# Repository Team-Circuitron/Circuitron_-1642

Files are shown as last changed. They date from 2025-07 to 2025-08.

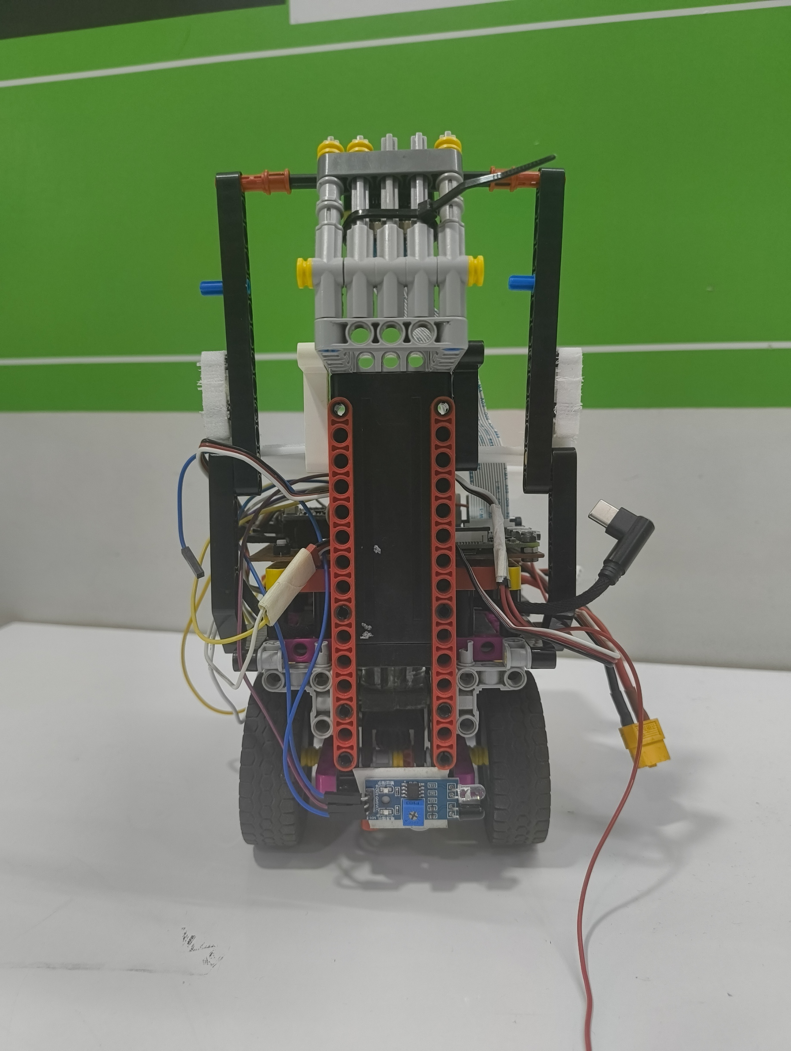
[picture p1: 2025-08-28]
v-photos/back view.jpg

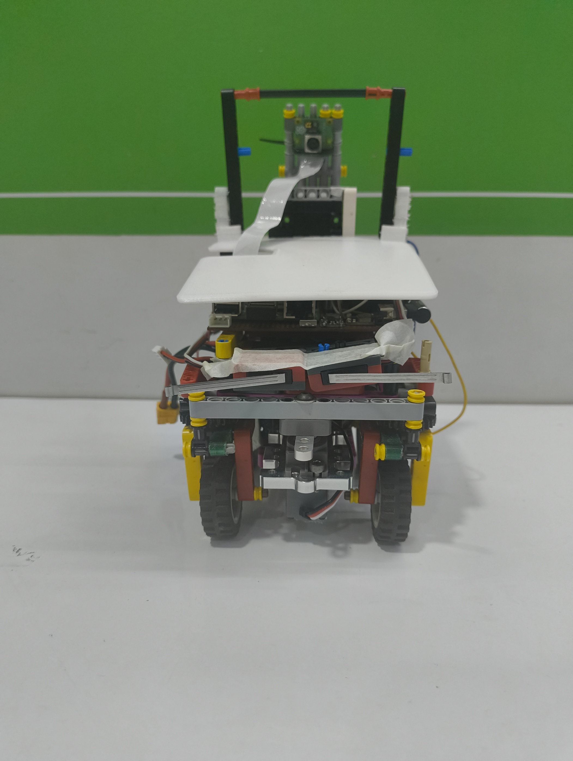
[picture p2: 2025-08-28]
v-photos/front view.jpg

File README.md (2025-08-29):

# Circuitron_#1642
**Contemplate · Create · Conquer**

This repository contains details about the design, evolution, and continuous development of our self-driving robot vehicle, built and programmed by Team Circuitron for the Future Engineers 2025 category of the World Robot Olympiad (WRO).

---

## Member Details
1. Pranay Agarwal (Software)  
2. Aditya Parikh (Hardware)  
3. Paritra Gada (Hardware)

---

## Table of Contents

- `t-photos`: Contains 2 photos of the team, including an official and a funny photo  
- `v-photos`: Contains 6 photos of the vehicle from all sides, including top and bottom views  
- `video`: Contains a `video.md` file linking to a video showing the robot in action  
- `Hardware`  Includes hardware overview, design process, final design, and component choices  
- `Code`: Includes all source code controlling the vehicle's behaviour 
- `Strategy`: Explanation of wall-following logic and decision-making approach  
- `models`  Files for 3D printing, laser cutting, or CNC (if applicable)  
- `other`: Supporting documents like connection instructions, datasets, specs  
- `special-thanks`  Acknowledgements and credits

---
## Engineering Notebook
Our engineering notebook contains more information about our robot and can be found here:

## Hardware Overview
---

## Table of Contents
1. [Hardware Overview](#hardware-overview)
2. [Processing Unit](#processing-unit)
3. [Vision System](#vision-system)
4. [Locomotion](#locomotion)
5. [Steering System](#steering-system)
6. [Power Management](#power-management)
7. [Chassis](#chassis)
8. [License](#license)

Our robotic platform is engineered with a modular hardware architecture  
to deliver high performance, flexibility, and support iterative development cycles.

---

## Processing Unit

**Raspberry Pi 4 Model B**

- CPU: Quad-core Cortex-A72 (ARM v8)
- RAM: 2GB / 4GB / 8GB (depending on configuration)
- Interfaces: GPIO, USB, HDMI, CSI (camera)

This board supports seamless integration of sensor arrays and enables  
Real-time control algorithms are essential for autonomous navigation and decision-making.

---

## Vision System

**Camera:** Raspberry Pi Camera Module

**Key Features:**
- Obstacle detection
- Line tracking
- Environmental mapping
- Native compatibility with the Raspberry Pi ecosystem

---

## Locomotion

**Wheels:** LEGO wheels for modularity and superior material quality  
**Motor:** D360 DC motor  

**Optimised for:**
- Size
- Weight
- Torque output
- Efficient mobility across diverse terrains

---

## Steering System

**Servo Motor:** [Insert Model] high-precision servo  

**Features:**
- Responsive and accurate control
- Reliable navigation in dynamic environments

---

## Power Management

**Buck Converter:** [Insert Model]  
**Input Voltage:** [Insert Voltage]V  

**Features:**
- Steps down the voltage to the required levels for all subsystems
- Ensures stable operation
- Protects sensitive electronics

---

## Chassis

**Framework:** LEGO-based chassis  

**Benefits:**
- Modularity for rapid iterations
- Ease of customisation
- Supports quick repositioning of components and continuous mechanical optimisation

## Strategy
Open Challenge Strategy
The Open Challenge begins with the robot aligning to the nearest wall and determining its driving orientation through initial line detection, where a blue line initiates anticlockwise motion and an orange line initiates clockwise motion. The robot applies wall-following algorithms to maintain a central path while incrementally counting laps using blue and orange corner lines, incorporating a debounce delay to prevent multiple counts per pass. Upon completion of three laps, confirmed by twelve line detections, the robot transitions into parking mode. It follows the outer black wall until detecting a pink wall, where it uses IMU feedback for angular correction and executes a precise parallel parking maneuver.

Obstacle Challenge Strategy
For the Obstacle Challenge, the robot begins within the parking zone and determines its initial direction based on black wall detection before exiting. During navigation, its vision system identifies red and green obstacles, steering right in the presence of red and left for green, while simultaneously applying wall-following and line detection for lap counting. After completing three laps, the robot performs an additional alignment lap to optimise its parking approach. Using IR sensors for accurate wall distance measurement and IMU-based angle corrections, the robot executes a reliable parallel parking sequence between two boundaries to conclude the challenge.

## Special Thanks
We are extremely grateful to our mentor, Mr. Sunil Solanki, for his invaluable guidance, encouragement, and belief in our abilities throughout this journey. His mentorship has been the driving force behind our learning and progress. We would also like to express our sincere gratitude to the honourable and venerable judges for giving us the privilege to present our work before such a distinguished panel. Your time, expertise, and dedication to this competition mean the world to us. It is an incredible honour to have our efforts reviewed by such esteemed individuals, and we deeply value this opportunity to showcase our passion, creativity, and hard work in robotics under your guidance.

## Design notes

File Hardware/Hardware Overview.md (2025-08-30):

# HARDWARE OVERVIEW
Detailed overview of the hardware architecture of our WRO Future Engineers robot.

---

##  Table of Contents
- [Overview](#overview)
- [Hardware Overview](#hardware-overview)
  - [Processing Unit](#processing-unit)
  - [Locomotion & Actuators](#locomotion--actuators)
  - [Motor Driver](#motor-driver)
  - [Power Management](#power-management)
  - [Sensors](#sensors)
  - [Camera System](#camera-system)
  - [Custom Electronics & PCB](#custom-electronics--pcb)
  - [Mechanical Structure](#mechanical-structure)
  - [User Interface](#user-interface)
- [Dimensions & Weight](#dimensions--weight)
- [Bill of Materials](#bill-of-materials)
- [Advantages](#advantages)

---

## Overview
Our robot is designed around **stability, modularity, and speed**.  
The hardware integrates:
- High-efficiency DC motors with optimised gearboxes  
- Raspberry Pi 4 for advanced vision and decision-making  
- Multiple feedback sensors (IMU, IR, Limit Switches)  
- Custom 3D-printed and LEGO-based chassis for compactness and modularity  
- Stable power distribution with buck converters and Li-ion batteries  

This ensures consistent performance across the **Obstacle Challenge** and **Open Challenge**.

---

## Hardware Overview

### Processing Unit
- **Raspberry Pi 4B (4GB RAM)**  
  - Central brain of the robot.  
  - Runs computer vision (OpenCV) and control algorithms in real time.  
  - Handles communication with sensors via I²C and GPIO.  
  - Selected for its balance of processing power, cost, and community support.  

---

### Locomotion & Actuators
The robot uses a carefully tested drive + steering system optimised for torque-speed balance.

- **Drive Motor: D360 Brushed DC Motor + 22:1 Gearbox**  
  - Provides sufficient torque for speed and manoeuvrability.  
  - Mounted in a **3D-printed housing** for vibration dampening and stable alignment.  

- **Steering: REV Robotics 2000 Series Dual Mode Servo**  
  - Dual functionality: can operate as a servo (angular control) or a continuous motor.  
  - Provides precise steering and a smooth turning radius.  
  - Mounted with GoBilda servo frame for durability.  

Other motors considered during iterations:  
- **N20 DC Motor** → lightweight but insufficient torque under load.  
- **REV NEO 550 Brushless** → powerful, but bulky and harder to tune with Spark MAX.  
- **LEGO Medium Motor** → easy integration but limited performance.  

Final choice balanced **speed, torque, and compactness** for competition.

---

### Motor Driver
- **TB6612FNG Dual H-Bridge Driver**  
  - Drives the brushed DC motor.  
  - Supports sufficient current with minimal heating.  
  - Provides braking and smooth acceleration.  

---

### Power Management
A robust power system ensures stability and prevents brownouts.

- **7.4V Li-ion Battery Pack (2S, 1300 mAh, 25C)**  
  - High energy density, rechargeable, stable voltage.  

- **Buck Converters**  
  - **5V 3A Buck Converter**: powers Raspberry Pi and sensors.  
  - **USB Step-Down Converter**: additional regulated output for Pi Camera and low-voltage peripherals.  
  - Efficient DC-DC regulation ensures minimal energy loss and protects sensitive electronics.  

---

### Sensors
The robot uses a combination of sensors for feedback and environment perception:

1. **Raspberry Pi Camera Module 3 (Wide)**  
   - Vision system for obstacle detection, wall following, lane recognition, and parking.  
   - Works with OpenCV for HSV-based color detection (red/green pillars, black walls, blue/orange lap lines, magenta parking zone).  

2. **BNO055 IMU**  
   - 9-axis (Gyroscope + Accelerometer + Magnetometer).  
   - Provides orientation for stable steering corrections.  
   - Runs built-in sensor fusion for accurate yaw, pitch, and roll readings.  

3. **IR Sensors (×4)**  
   - Used for short-range obstacle detection and alignment during parking.  

4. **VEX Limit Switches**  
   - Detect physical collisions or if the robot gets stuck.  
   - Provides fail-safe redundancy.  

---

### Camera System
- **Raspberry Pi Camera Module 3 (Wide-Angle)**  
  - Mounted on the front of the robot.  
  - Wide field of view enables simultaneous wall, obstacle, and marker detection.  
  - Paired with OpenCV for real-time image processing.  

---

### Custom Electronics & PCB
- Soldered a zero board to ensure strong connections and reliability 
- Functions:  
  - Power distribution from battery to buck converters.  
  - Organised sensor and motor connections.  
  - Reduced wiring complexity and improved reliability.
Picture of the Circuit diagram is attached

---

### Mechanical Structure
- **Chassis**: hybrid of LEGO Technic and 3D-printed parts.  
- **Design goals**: compact, modular, easy to modify.  
- **3D-Printed Custom Components**:  
  - Motor mounts for vibration reduction.  
  - Camera housing to block false detections from internal circuits.  
  - Protective covers for sensitive electronics.  

---

### User Interface
- **Push Buttons**  
  - Start/Stop robot.  
  - Emergency reset if required.  

---

## Dimensions & Weight
- **Weight**: ~650–700 g  
- **Dimensions**: ~16 cm (L) × 12 cm (W) × 10 cm (H)  

Compact enough for agility while maintaining balance during turns.

---

## Bill of Materials
| Component | Quantity | Source/Link |
|---|---|---|
| Raspberry Pi 4B (4GB) | 1 | [Robu.in](https://robu.in/product/raspberry-pi-4-model-b-with-4-gb-ram/) |
| Raspberry Pi Camera Module 3 (Wide) | 1 | [Robu.in](https://robu.in/product/raspberry-pi-camera-module-3-wide/) |
| D360 Brushed DC Motor + Gearbox | 1 | [Temu](https://www.temu.com/goods_snapshot.html?goods_id=601099518898704) |
| TB6612FNG Motor Driver | 1 | [Robu.in](https://robu.in/product/motor-driver-tb6612fng-module) |
| REV 2000 Series Servo | 1 | [GoBilda](https://www.gobilda.com/2000-series-dual-mode-servo-25-4-super-speed/) |
| GoBilda Servo Mount | 1 | [GoBilda](https://www.gobilda.com/1802-series-servo-frame-43mm-width-for-standard-size-servos/) |
| 7.4V 2S Li-ion Battery Pack (1300 mAh, 25C) | 1 | [Robu.in](https://robu.in/product/orange-1300mah-2s-25c-7-4-v-lithium-polymer-battery-pack-li-po/) |
| Buck Converter (5V, 3A) | 1 | [Robu.in](https://robu.in/product/ultra-small-size-dc-dc-5v-3a-bec-power-supply-buck-step-down-module/) |
| USB Buck Converter | 1 | [Robu.in](https://robu.in/product/dc-to-dc-6-24v-to-5v-usb-output-step-down-power-charger-buck-converter/) |
| BNO055 IMU | 1 | [ThinkRobotics](https://thinkrobotics.com/products/9-dof-absolute-orientation-bno055-sensor) |
| VEX Limit Switches | 2 | [VEX Robotics](https://www.vexrobotics.com/276-2174.html) |
| IR Sensors | 4 | [Robu.in](https://robu.in/product/ir-infrared-obstacle-avoidance-sensor-module/) |
| LEGO Technic Parts | Multiple | — |
| 3D Printed Parts | Custom | — |

---

## Advantages
- **High Performance**: Custom D360 motor with gearbox tuned for speed + torque.  
- **Vision-Driven**: Pi Camera enables wall following, lap counting, and obstacle navigation.  
- **Failsafe Redundancy**: Limit switches prevent deadlocks if the robot gets stuck.  
- **Stable Power**: 5V regulation avoids Pi brownouts.  
- **Compact & Modular**: Hybrid LEGO + 3D printed structure supports quick modifications.  
- **Reliable Navigation**: BNO055 IMU stabilizes turns and corrections.  
- **Consistent Parking**: IR sensors ensure accurate parallel parking.  

---
## Why did we use a custom motor
Our motor is based on the D360 DC motor with a custom gearbox. We used this motor because we could not find any other motor that had the appropriate speed, torque, and weight. We found that using a custom motor was the best choice.

## Why did we use a white cover
Frequently, our camera would detect the electronics on our PCB as obstacles or walls. Therefore, we found that the best way to overcome this was to put a white cover over our PCB, so that our camera would not be confused by the colours on our PCB.

## Why did we feel that LEGO was the best option
The lego chassis is completly custom designed from scratch, and we found it was the best option as it gave us the flexibility to use whichever parts we want and the lego chassis is extremly modular in comparison to other of the shelf options. Lego parts are also strong and the chassis is extremly easy to change or repair at a moments notice in comparison to off the shelf options.

##CAD and Lego
The instructions for building our robot are provided in this repository [Robot Assembly Instructions](Robot_Assembly_Instructions.pdf). We have also attached an Excel sheet containing all the LEGO parts required to make the robot. We have also attached the CAD files, the cover and the custom housing in this repository. The complete CAD of the robot is also attached in a .io file format, as the CAD was made in LEGO Studio. The cad for the custom parts is given in STEP format, as that was made in onshape.

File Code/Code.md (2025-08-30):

 Below is the Obstacle Challenge Code and its explanation: 
---
from picamera2 import Picamera2

import cv2

import numpy as np

import time

import pigpio

import datetime

import board

import adafruit_bno055

import RPi.GPIO as GPIO
---
[The above consists of all the libraries and modules utilised by the team in the code. 

Picamera2: Allows us to communicate with the Picam 3 and set values such as exposure and frame rate

cv2: A vision software allowing us to perform image manipulation, draw contours and calculate the area, x, y and other factors relating to the object

numpy: Allows the team to store HSV values in arrays

time: Allows the team to add time based movements and set timers

pigpio: Allows the team to control the motors and servos accurately

datetime: Allows the team to capture the camera preview, and save it with the current date and time

board: Allows 12C communication

adafruit_bno055: Allows the team to communicate and gain data drom the IMU

RPi.GPIO: Allows the team to directly attach IR sensors and Limit Switches to the GPIO pins easily]

# === I2C & sensors ==
i2c = board.I2C()

sensor = adafruit_bno055.BNO055_I2C(i2c)

[IMU setup]

offset = 0

prev_heading = None

total_heading = 0

(Global variables for IMU)

# === Pin and hardware config ===
MOTOR_PIN_1 = 24 #Motor Driver PIN1

MOTOR_PIN_2 = 23 #Motor Driver PIN2

MOTOR_ENA = 18 #Motor Driver Enable Pin

SERVO_PIN = 25 #Servo Out Pin

BUTTON_START = 14 #Button 1 Digital Input Pin

BUTTON_STOP = 15 #Button 2 Digital Input Pin

[Teams may change these pins as per their needs]

# Motor PWM frequency
MOTOR_PWM_FREQ = 1000

BUTTON_PIN = 26  # Limit Switch (Left) Out Pin

GPIO.setmode(GPIO.BCM)

GPIO.setup(BUTTON_PIN, GPIO.IN, pull_up_down=GPIO.PUD_UP) # (Limit Switch (Left) Setup

GPIO.setup(12,GPIO.IN,pull_up_down=GPIO.PUD_UP) # (Limit Switch (Right) Setup)

GPIO.setup(21,GPIO.IN) # (IR Sensor Right Back Setup)

GPIO.setup(20,GPIO.IN) # (IR Sensor Right Front Setup)

GPIO.setup(16,GPIO.IN) # (IR Sensor Left Front Setup)

GPIO.setup(19,GPIO.IN) # (IR Sensor Left Back Setup)

[Teams may change the pin numbers as per their requirements] 

# Speed settings (0-255 PWM duty cycle)

SPEED_RUN = 80 

SPEED_RUN_SLOW = 75

SPEED_STOP = 0

[Teams may change the SPEED_RUN to make their robot faster or slower]
# Steering angles (degrees)

STEER_CENTER = 110

STEER_LEFT_LIMIT = 78

STEER_RIGHT_LIMIT = 142

[The above are variables referring to the positions the servo is at, at the centre, left and right]

# Steering adjustment factors (tuning)

STEER_FACTOR_GREEN_HIGH =0.09

STEER_FACTOR_GREEN_LOW = 0.07

STEER_FACTOR_RED_HIGH = 0.09

STEER_FACTOR_RED_LOW = 0.07

STEER_FACTOR_BLACK_DIFF = 0.07

STEER_FACTOR_SINGLE_TARGET = 0.08

STEER_FACTOR_OUTER_ROUND=0.04

STEER_FACTOR_LEFT_Y_DIFF = 0.07

[The above are Kp values that teams shall have to adjust based on their robot for different aspects of the code]
# Camera settings

EXPOSURE_TIME =13000 #Brightness setting for the PiCam3

X_RESOL = 1080 #Screen width

Y_RESOL = 300 #Screen Length

X_MID = X_RESOL / 2 #Middle of the screen

LEFT_LIMIT = 10 #Lefmost limit of the screen

RIGHT_LIMIT = X_RESOL - 10 #Rightmost limit of the screen

[Teams may change the X_RESOL or Y_RESOL, if not enough is visible from a point or if too many objects are being detected]

# HSV thresholds for colors
GREEN_LOWER = np.array([50, 100, 50])

GREEN_UPPER = np.array([70, 255, 255])

RED_LOWER1 = np.array([0, 120, 50])

RED_UPPER1 = np.array([10, 255, 255])

RED_LOWER2 = np.array([160, 120, 50])

RED_UPPER2 = np.array([165, 255, 255])

PINK_LOWER = np.array([160, 100, 120])

PINK_UPPER = np.array([175, 255, 255])

BLACK_LOWER = np.array([0, 0, 0])

BLACK_UPPER = np.array([179, 255, 50])

BLUE_LOWER = np.array([100, 150, 50])
BLUE_UPPER = np.array([130, 255, 255])

ORANGE_LOWER = np.array([10, 150, 100])

ORANGE_UPPER = np.array([25, 255, 255])

PURPLE_LOWER = np.array([160, 80, 40])

PURPLE_UPPER = np.array([175, 255, 200])

[The above are the Hue, Saturation and Value features required for the detection of the black walls, obstacle, orange and blue lines and parking zone. If the HSV values are not sufficient for the given detection, teams may modify them]

# Line detection parameters
LINE_COOLDOWN = 3.5  # seconds cooldown before recounting same line [Teams may adjust this in case the lines are being detected repeatedly or not at all]

LINE_DETECT_REGION_Y =Y_RESOL-50  # y coordinate near bottom to detect line crossing [Teams may adjust this distance based on their camera position]
 
ParkOver=False # [Our team starts in the parking zone, thus, this variable signals for the exit manuever to start, teams may change this to true if they do not wish to start in the parking zone]

# Line counting mode: 'blue', 'orange', or 'both'
LINE_COUNT_MODE = 'both'  # Change this to 'blue' or 'orange' as needed [For redundancy, the team takes the highest count of the line detected, (eg- Orange count=10, Blue Line count=9, the round count shall be taken as 10. If the team wishes to only look for 1 line (orange or blue), they may change it to 'orange' or 'blue' accordingly]

# === Initialize PiCamera2 ===
picam2 = Picamera2()

preview_config = picam2.create_preview_configuration(main={"format": 'RGB888', "size": (X_RESOL, Y_RESOL)})

picam2.preview_configuration.controls.FrameRate = 60 #Teams may increase this to a maximum of 660 fps if they feel detection rate is not fast enough.]

picam2.configure(preview_config)

picam2.set_controls({

    "AeEnable": False,
    
    "ExposureTime": EXPOSURE_TIME,
    
    "AnalogueGain": 4.0
})

timestamp = datetime.datetime.now() # [The team would save the preview of the video recorded by the camera, and would be saved by the time of recording. In case teams feel they do not need this, they may decided to remove it]

video = cv2.VideoWriter(f"output{timestamp}.mp4", cv2.VideoWriter_fourcc(*"mp4v"), 20, (X_RESOL, Y_RESOL))

picam2.start() #Start camera

time.sleep(1) # Note- [The camera takes a minimum of 1 second to setup, do not decrease the value]

# === Setup GPIO pins ===
pi = pigpio.pi() 

pi.set_mode(BUTTON_START, pigpio.INPUT) # [Setup for the button pin1]

pi.set_pull_up_down(BUTTON_START, pigpio.PUD_UP) # [Setmode for button pin1]

pi.set_mode(BUTTON_STOP, pigpio.INPUT) # [Setup for the button pin2]

pi.set_pull_up_down(BUTTON_STOP, pigpio.PUD_UP) # [Setmode for button pin2]

for pin in (MOTOR_PIN_1, MOTOR_PIN_2, MOTOR_ENA): # [Setup of motor pins]
    pi.set_mode(pin, pigpio.OUTPUT)
    pi.write(pin, 0)

pi.set_PWM_frequency(MOTOR_ENA, MOTOR_PWM_FREQ) # [PWM frequency for speed setting]

# === Robot control functions ===
def steer(angle: float): #[Set angle for servo position function]

    """Set servo angle within limits."""
    
    angle = max(STEER_LEFT_LIMIT, min(STEER_RIGHT_LIMIT, angle)) 
    
    #[In any case if the angle written in the function is less or greater than the limit, the angle is set accordingly either to the STEER_LEFT_LIMIT or STEER_RIGHT_LIMTI ]
    
    pulse = int(500 + (angle / 180) * 2000) [Conversion from pulse to degrees, requesting teams not to change this]
    
    pi.set_servo_pulsewidth(SERVO_PIN, pulse)
    
    # [The above function allows one to easily set the angle of the servo by calling the steer() function]

def run(speed: int): # [Run motor forward at a given speed]

    """Run motors forward at speed (0-255)."""
    
    pi.write(MOTOR_PIN_1, 1) #Teams may have to reverse this based on their MOTOR_PIN_1 and MOTOR_PIN_2 connections
    
    pi.write(MOTOR_PIN_2, 0)
    
    pi.set_PWM_dutycycle(MOTOR_ENA, speed)
    
#The above function allows one in the code to set the speed for the forward direction by calling the function run()

def back(speed: int): [#Run motor backward at a given speed]

    """Run motors backward at speed (0-255)."""
    
    pi.write(MOTOR_PIN_1, 0)  #Teams may have to reverse this based on their MOTOR_PIN_1 and MOTOR_PIN_2 connections
    
    pi.write(MOTOR_PIN_2, 1)
    
    pi.set_PWM_dutycycle(MOTOR_ENA, speed)

#The above function allows one in the code to set the speed for the reverse direction by calling the function back()

def stop_motors():

    """Stop all motors."""

    pi.set_PWM_dutycycle(MOTOR_ENA, 0)
    
    pi.write(MOTOR_PIN_1, 0)
    
    pi.write(MOTOR_PIN_2, 0)

    # The above function stops the motors and locks them in place and can be called by the function stop_motors()
    
def reset_heading():

    global prev_heading,total_heading
    
    prev_heading = None

    total_heading = 0

    #In order to reset the IMU before parking, this function may be called. The total heading is reset back to 0 allowing for accurate data readings. This function may be called by reset_heading()
    
def get_heading():

    global total_heading,prev_heading
    
    try:
        time.sleep(0.03) # [Requesting teams to not edit this, as this delay may cause great changes in sensor readings]
        
        current_heading = sensor.euler[0] # [The heading is returns other values such as acceleration and speed as well, [0], gives access to the angle]
        
        if current_heading is None:
            return total_heading # [If no reading is available, return 0]

        if prev_heading is None: # [Keep updating prev_heading, in order to get the change in heading (delta)]
            prev_heading = current_heading
            return total_heading

        delta = current_heading - prev_heading
        if delta > 180: #[Limit delta to 180 and -180)
            delta -= 360
        elif delta < -180:
            delta += 360

        total_heading += delta #[Keep updating total heading]
        prev_heading = current_heading
        return total_heading #[return the value]
    except Exception as e: # [In case there is an error in the reading, simply return the total_heading]
        print("Error reading heading:", e) 
        return total_heading
    # [The above function allows one to gain the angle of the robot in terms of degrees accurately by calling the function get_heading()]
def get_red_mask(hsv):

    """Get combined red mask handling hue wrap."""
    mask1 = cv2.inRange(hsv, RED_LOWER1, RED_UPPER1)
    mask2 = cv2.inRange(hsv, RED_LOWER2, RED_UPPER2)
    return cv2.bitwise_or(mask1, mask2)
    # [The above function allows for a more neat and systematic detection by using functions. Teams should be advised to not change this. Function is called by get_red_mask()]
    
# === Global variables for line counts and cooldown ===
blue_line_count = 0 #How many times blue line is detected

orange_line_count = 0 #How many times orange line is detected

last_blue_time = 0 #Time when the blue line was last detected

last_orange_time = 0 #Time when the orange line was last detected

[In order to avoid detecting the same line repeatedly a time based logic is used which limits the camera reading to the line]

# Rounds & stopping control
rounds_completed = 0 #Currently how many rounds have been completed

insidePark=True #Is the robot currently between the parallel walls? Note- [If it is not wished to start in parking zone, the variable may be set to 'False']

targ1 = True #Completion of turn 1

targ2 = True #Completion of turn 2

targ3=True #Completion of turn 3

targ4=True # Completion of turn 4

     # [targ1,2,3,4 ensure that the turns to exit the parking zone only occur once after which, the next turn happens]

selected = False # Is direction set?
    # [The team establishes direction on the basis of the position of the black walls in the very start, after which it is set to 'True' to ensure this process occurs only once. If teams wish to preset a direction, they may set selected to 'True' and accordingly set CLOCKWISE as 'true' or 'false'

CLOCKWISE = True # default direction

over = False # Should the robot start parking?  # [If teams wish to only test the parking, they may set over to 'True']

parked = False # Is parking done? # [If teams wish to disable the parking, they may set parked to 'True']

# === Main processing function ===
def process_frame():

    global ButtonTime, Reset, STEER_FACTOR_OUTER_ROUND
    
    global blue_line_count, orange_line_count, last_blue_time, last_orange_time,purple_target
    
    global rounds_completed,selected,CLOCKWISE
    
    global targ1,targ2,insidePark,targ3,targ4,parked,over

    #Use the variables set in initialization
    
    frame = picam2.capture_array() #Set the frame for the picamera
    
    hsv = cv2.cvtColor(frame, cv2.COLOR_BGR2HSV) # Set hsv value on the basis of the frame
    
    blur = cv2.GaussianBlur(hsv, (5, 5), 0) #Apply a Gaussian blur to eliminate random detections

    #Note- [Teams are advise to not change the frame, hsv and blur variables]
    
    current_time = time.time() #[Constantly set the timer functoion in the code in order for the line debouncing logic]
    
    black_mask = cv2.inRange(blur, BLACK_LOWER, BLACK_UPPER)
    
    green_mask = cv2.inRange(blur, GREEN_LOWER, GREEN_UPPER)
    
    red_mask = get_red_mask(hsv)
    
    pink_mask = cv2.inRange(blur, PINK_LOWER, PINK_UPPER)
    
    blue_mask = cv2.inRange(hsv, BLUE_LOWER, BLUE_UPPER)
    
    orange_mask = cv2.inRange(hsv, ORANGE_LOWER, ORANGE_UPPER)
    
    purple_mask = cv2.inRange(hsv, PURPLE_LOWER, PURPLE_UPPER)
    
    kernel_5 = np.ones((5, 5), np.uint8)
    
    kernel_50 = np.ones((50, 50), np.uint8)

    black_mask = cv2.morphologyEx(black_mask, cv2.MORPH_CLOSE, kernel_50)
    
    black_mask = cv2.morphologyEx(black_mask, cv2.MORPH_DILATE, kernel_50)
    
    blue_mask = cv2.morphologyEx(blue_mask, cv2.MORPH_CLOSE, kernel_5)
    
    orange_mask = cv2.morphologyEx(orange_mask, cv2.MORPH_CLOSE, kernel_5)

    #The masks set the hsv range and values as defined earlier in the initialization process. The kernels allow for object definition and setting the centre point of the object detected.

    # Blue line detection
    global ParkOver
    blue_detected = False
    blueDone=0
    if LINE_COUNT_MODE in ('blue', 'both'):
        contours_blue, _ = cv2.findContours(blue_mask, cv2.RETR_EXTERNAL, cv2.CHAIN_APPROX_SIMPLE) # draw a contour over the blue line detected
        for cnt in contours_blue:
            if cv2.contourArea(cnt) > 1000 and ParkOver: # [only detect if getting out of the parking zone is over and the min. area for detection > 1000]
                x, y, w, h = cv2.boundingRect(cnt)
                if y + h >= LINE_DETECT_REGION_Y: # [Only within a certain distance should the contour be made]
                    blue_detected = True
                    cv2.rectangle(frame, (x, y), (x + w, y + h), (255, 0, 0), 2)
                    break

    # Orange line detection
    orange_detected = False
    orangeDone=0
    if LINE_COUNT_MODE in ('orange', 'both'):
        contours_orange, _ = cv2.findContours(orange_mask, cv2.RETR_EXTERNAL, cv2.CHAIN_APPROX_SIMPLE)  # draw a contour over the orange line detected
        for cnt in contours_orange:
            if cv2.contourArea(cnt) > 1000 and ParkOver:  # [only detect if getting out of the parking zone is over and the min. area for detection > 1000]
                x, y, w, h = cv2.boundingRect(cnt)
                if y + h >= LINE_DETECT_REGION_Y: # [Only within a certain distance should the contour be made]
                    orange_detected = True
                    cv2.rectangle(frame, (x, y), (x + w, y + h), (0, 140, 255), 2)
                    break

    if blue_detected and (current_time - last_blue_time) > LINE_COOLDOWN:
    
    #only register if the line has been detected if the time between the previous detection and the current time is greater than the cooldown time]
    
        if GPIO.input(26)==GPIO.LOW or GPIO.input(12)==GPIO.LOW:
        
        """Since the limit switches are generally triggered at the corner, and thus due to the reverse, we count the lines twice, we added a line_count depletion condition to avoid miscount. If teams find this to not be a problem they may remove this]"""
        
            blue_line_count-=1
            
        blue_line_count += 1
        
        last_blue_time = current_time
        
        print(f"Blue line crossed! Count: {blue_line_count}")

    if orange_detected and (current_time - last_orange_time) > LINE_COOLDOWN:
    
       #only register if the line has been detected if the time between the previous detection and the current time is greater than the cooldown time]
       
        if GPIO.input(26)==GPIO.LOW or GPIO.input(12)==GPIO.LOW:
                """Since the limit switches are generally triggered at the corner, and thus due to the reverse, we count the lines twice, we added a line_count depletion condition to avoid miscount. If teams find this to not be a problem they may remove this]"""
                
            orange_line_count-=1
            
        orange_line_count += 1
        
        last_orange_time = current_time
        
        print(f"Orange line crossed! Count: {orange_line_count}")
    
    # Calculate rounds completed
    if LINE_COUNT_MODE == 'blue':
    
        rounds_completed = blue_line_count

    elif LINE_COUNT_MODE == 'orange':
    
        rounds_completed = orange_line_count
        
    else:  # both
    
        rounds_completed = max(blue_line_count, orange_line_count) # [Condition for maximum round count]

    # [The above condition allows the classification of the line count on the basis of 'both' or 'orange' or 'blue' 

    # Find black contours for navigation
    contours, _ = cv2.findContours(black_mask, cv2.RETR_EXTERNAL, cv2.CHAIN_APPROX_SIMPLE)
    
    left_target = None
    
    right_target = None
    
    max_left_y = 0 # Detection for left wall
    
    max_right_y = 0 #Detection for right wall

    for contour in contours:
    
        area = cv2.contourArea(contour)
        
        if area > 1000:
        
            x, y, w, h = cv2.boundingRect(contour)
            
            cx = int(x + w / 2)
            
            cy = int(y + h / 2)
            
            cv2.rectangle(frame, (x, y), (x + w, y + h), (180, 105, 255), 2) # [Draw a contour around the middle of the detected portion]
            
            cv2.circle(frame, (cx, cy), 5, (255, 0, 0), -1) # [Draw a dot indicating the centre]
            
            if not selected:
            # [Classification of direction- clockwise or anticlockwise]

                """ [Since we start inside the parking zone, the right wall is always in closer to us, thus, on the basis of where the larger black contour is detected, we may establish the direction]"""
                
                if cx < X_MID: # [Our screen ranges from 0 to 1080, from the left to right. Thus, if the detected portion is on the left, direction is clockwise]
                
                    CLOCKWISE = True
                else: # [ if the detected portion is on the left, direction is clockwise, else it must be anticlockwise [CLOCKWISE='False' ]]
                
                    CLOCKWISE = False
                    
                selected = True # [The process of find direction should only occur once.]
                
            if CLOCKWISE: #If direction is CLOCKWISE
                if cx <= X_MID + 10 and cy > max_left_y:
                
                """[X_MID+10 gives some error range for camera fluctuations, teams may have to increase or decrease this. cy>max_left_y ensures only the closest reading is taken into consideration after which its value (initially 0), is updated to the current cy]"""
                
                    max_left_y = cy
                    
                    left_target = (x + w, y + h) # (cx and cy values. since the y+h of the wall gives overall cy and similarly for cx)
                    
                elif cx > X_MID + 10 and cy > max_right_y: 
                ("Opposite if detectrd refion is in the right)
                
                    max_right_y = cy
                    
                    right_target = (x, y + h) # (Since the target is on the right, no additional w is needed)
                    
            else: 
            
                    """[X_MID-10 gives some error range for camera fluctuations, teams may have to increase or decrease this. cy>max_left_y ensures only the closest reading is taken into consideration after which its value (initially 0), is updated to the current cy]"""
                
                if cx >= X_MID - 10 and cy > max_right_y: 
                
                    max_right_y = cy
                    
                    right_target = (x, y + h) # (Since the target is on the right, no additional w is needed)
                    
                elif cx < X_MID - 10 and cy > max_left_y: 
                
                    max_left_y = cy
                    
                    left_target = (x + w, y + h) # (Since the target is on the left, an additional w is required)
                
    # Detect green obstacles
    green_contours, _ = cv2.findContours(green_mask, cv2.RETR_EXTERNAL, cv2.CHAIN_APPROX_SIMPLE)
    
    green_target = None
    
    green_y = 0
    
    for c in green_contours:
    
        area = cv2.contourArea(c)
        
        if 1000 < area <= 20000: # Ensure that the detected area is not a wall or some other object
        
            x, y, w, h = cv2.boundingRect(c)
            
            cx = x # Since we have to go to the left of green, we simply take cx as x.
            
            cy = y + h #The object's h must also be taken into consideration for the total y distance
            
            cv2.rectangle(frame, (x, y), (x + w, y + h), (0, 255, 0), 2) # Draw a contour around the detected region
            
            cv2.circle(frame, (cx, cy), 5, (255, 0, 0), -1) # Draw a dot at the bottom left corner
            
            cv2.putText(frame, f"Green Obstacle: {cy}", (x, y - 10), cv2.FONT_HERSHEY_SIMPLEX, 0.6, (0, 255, 0), 2) #print the cy on the screen
            
            if CLOCKWISE:
                if cy > green_y: # Detect only the closest obstacle
                    green_y = cy
                    green_target = (cx, cy)
                    if rounds_completed >= 12:
                        right_target = (cx, cy) # [We take an outer left round before park. Due to this, during that we establish any obstacle as a right wall]
            else:
                if cy > green_y:  # Detect only the closest obstacle
                    green_y = cy
                    green_target = (cx, cy)
                    if rounds_completed >= 12:
                        left_target = (cx, cy) # [We take an outer right round before park. Due to this, during that we establish any obstacle as a left wall]
            
    # Detect red obstacles
    red_contours, _ = cv2.findContours(red_mask, cv2.RETR_EXTERNAL, cv2.CHAIN_APPROX_SIMPLE)
    red_target = None
    red_y = 0
    for c in red_contours:
        area = cv2.contourArea(c)
        if area > 1000: #Ensure a minimum area of detection
            x, y, w, h = cv2.boundingRect(c)
            cx = x + w #Since we have to go on the right side, we add an offset of w, the objects pixel width as seen on the screen
            cy = y + h
            cv2.rectangle(frame, (x, y), (x + w, y + h), (0, 0, 255), 2) #Draw a contour around it
            cv2.circle(frame, (cx, cy), 5, (255, 0, 0), -1) # Put a point on the bottom right corner
            cv2.putText(frame, f"Red Obstacle:{cy}", (x, y - 10), cv2.FONT_HERSHEY_SIMPLEX, 0.6, (0, 0, 255), 2) # print the cy on the screen
            if CLOCKWISE:
                if cy > red_y:
                    red_y = cy
                    red_target = (cx, cy)
                    if rounds_completed >= 12:
                        right_target = (cx,cy)  # [We take an outer left round before park. Due to this, during that we establish any obstacle as a right wall]
            else:
                if cy > red_y :
                    red_y = cy
                    red_target = (cx, cy)
                    if rounds_completed >= 12:
                        left_target = (cx,cy) # [We take an outer right round before park. Due to this, during that we establish any obstacle as a left wall]

    current_time = time.time()
    # start the timer once again
    purple_detected = False
    purple_target = None
    
    contours_purple, _ = cv2.findContours(purple_mask, cv2.RETR_EXTERNAL, cv2.CHAIN_APPROX_SIMPLE)
    for cnt in contours_purple:
        x, y, w, h = cv2.boundingRect(cnt)         
        if cv2.contourArea(cnt) > 1000: # Ensure a minimum areA
            if CLOCKWISE:
                purple_detected = True
                cv2.rectangle(frame, (x, y), (x + w, y + h), (180, 105, 255), 2) # draw contour around the detected region
                cv2.circle(frame, (x+w, y), 5, (255, 0, 0), -1) # draw a point on the top right corner
                left_target = (x+w, y) # In case the rounds are still going on, set the purple area as black wall on the left (CLOCKWISE)
                purple_target = (x+w, y) # Set purple's reference point as top right corner on the wall
            else:
                purple_detected = True
                cv2.rectangle(frame, (x, y), (x + w, y + h), (180, 105, 255), 2) # draw contour around the detected region
                cv2.circle(frame, (x, y), 5, (255, 0, 0), -1) # draw a point on the top left corner of the wall
                right_target = (x, y) # In case the rounds are still going on, set the purple area as black wall on the right (ANTICLOCKWISE)
                purple_target = (x, y) # Set purple's reference point as top left corner on the wall
            
    if not over: # if the 4th round is not over and purple has not been detected
        print("Heading : ",get_heading()) # print heading for redundancy . Teams may remove this
        if insidePark: # if robot is inside the parking zone
            if CLOCKWISE:
                if abs(get_heading()) < 20 and targ1: # turn1 towards the left, slightly backwards (Decrease if hitting the back wall, increase if too less)
                    steer(72)
                    back(85)
                elif abs(get_heading()) < 50 and targ2: #turn2 towards the right, forwards (Increase if too less, decrease if too much)
                    targ1 = False
                    steer(148)
                    run(85)
                elif abs(get_heading())>5 and targ3: # turn3 towards the left forwards (Decrease if too much, Increase if too less)
                    targ2=False
                    steer(72)
                    run(85)
                else:
                #Note-[Teams shall have to change the 20,50 and 5 values based on the imu position, robot's length and imu orientation]
                    targ3=False
                    if targ3==False and targ4:
                        run(0)
                        steer(110)
                        time.sleep(0.5)
                        back(100) #come back for a fixed duration to avoid accidentally crossing over an obstacle
                        time.sleep(1.1) # (teams may have to change this value)
                        targ4=False
                        insidePark=False
                        time.sleep(0.5)
                        stop_robot()
                        
            else:
                if abs(get_heading()) <15 and targ1: # turn1 towards the right, slightly backwards (Decrease if hitting the back wall, increase if too less)
                    steer(148)
                    back(85)
                
                elif abs(get_heading()) <50 and targ2: #turn2 towards the left, forwards (Increase if too less, decrease if too much)
                    targ1 = False
                    steer(72)
                    run(85)
                elif abs(get_heading()) >10 and targ3: # turn3 towards the right forwards (Decrease if too much, Increase if too less)
                    targ2=False
                    steer(148)
                    run(85)                                 
                else:
                 #Note-[Teams shall have to change the 15,50 and 10 values based on the imu position, robot's length and imu orientation]
                    targ3=False
                    targ2 = False
                    if targ3==False and targ4:
                        run(0)
                        steer(110)
                        time.sleep(0.5)
                        back(100) #come back for a fixed duration to avoid accidentally crossing over an obstacle
                        time.sleep(1.1) # (teams may have to change this value)
                        targ4=False
                        insidePark=False
                        run(0)
                        time.sleep(0.45)
                        stop_robot()
                        time.sleep(0.5)
                        ParkOver=True
                        
        elif GPIO.input(12)==GPIO.LOW: # If the right limit switch is pressed, the robot shall turn towards the right and come back slightly for redundancy
            run(0)
            time.sleep(0.3)
            steer(STEER_RIGHT_LIMIT) 
            time.sleep(0.4)
            back(90)
            time.sleep(0.5) # teams may have to change the back time
            run(0)
            time.sleep(0.4)
            steer(110)
            time.sleep(0.4)

        elif GPIO.input(26)==GPIO.LOW:
            run(0)
            time.sleep(0.3)
            steer(STEER_LEFT_LIMIT)
            time.sleep(0.4)
            back(90) # teams may have to change the back time
            time.sleep(0.5)
            run(0)
            time.sleep(0.4)
            steer(110)
            time.sleep(0.4)
      #The above GPIO 26 and GPIO 12 functions are for backup purposes. Teams can remove them if they wish to.

        elif purple_detected and rounds_completed >= 14: # if the outer round is completed and purple is detected
            run(60)
            only_x, only_y = purple_target
            if CLOCKWISE: # Keep Purple On left when clockwise
                steer(STEER_CENTER + ((only_x - 420) * STEER_FACTOR_SINGLE_TARGET))# change the servo angle from centre to required angle)
            else: #keep purple on right when anticlockwise
                steer(STEER_CENTER + ((only_x - 750) * STEER_FACTOR_SINGLE_TARGET))# change the servo angle from centre to required angle)
            if (GPIO.input(21)==GPIO.LOW) or (GPIO.input(16)==GPIO.HIGH): 
            
            """Detection via IR Sensor. Since the IR sensor cannot detect the black walls, but can detect the pink walls, after the outer round is over and the camera has seen the parking zone, we may reliably move forward via the IR sensor"""
            
                over = True # Start parking
                steer(STEER_CENTER)
                stop_robot()
                time.sleep(2) 

        elif green_target and red_target and rounds_completed <=12: # if rounds completed is less than 13 and both red and greeen is detected
            run(SPEED_RUN)
            if green_y > red_y: # (If green is closer than red, follow green)
                right_x, right_y = green_target
                if right_y > 100: # (Until the robot is not within a certain range, keep green in the centre of the screen and follow (540))
                    steer(STEER_CENTER + ((right_x - 820) * STEER_FACTOR_GREEN_HIGH)) 
                    # (In order to go to the left, green must be on the right, thus, the error is green's current x - the required position (820 on the screen)
                    # (This error is multiplied by a constant to give an output servo position)
                else:
                    steer(STEER_CENTER + ((right_x - 540) * STEER_FACTOR_GREEN_LOW))
                    #(Until the robot is close enough, try to set the obstacle in the centre of the screen)
            else:
                left_x, left_y = red_target
                if left_y > 100: #(Until the robot is not within a certain range, keep green in the centre of the screen and follow (540))
                    steer(STEER_CENTER + ((left_x - 260) * STEER_FACTOR_RED_HIGH))
                    # (In order to go to the right, red must be on the left, thus, the error is red's currrent x- the required position (260 on the screen)                            # (This error is multiplied by a constant to give an output servo position)    
                else:
                    steer(STEER_CENTER + ((left_x - 540) * STEER_FACTOR_RED_LOW))
                    #(Until the robot is close enough, try to set the obstacle in the centre of the screen)
                    
        elif green_target and rounds_completed <= 12:
            run(SPEED_RUN)
            if CLOCKWISE:
                right_x, right_y = green_target
                if right_y > 100:
                    steer(STEER_CENTER + ((right_x - 820) * STEER_FACTOR_GREEN_HIGH))
                else:
                    steer(STEER_CENTER + ((right_x - 540) * STEER_FACTOR_GREEN_LOW))
            else:
                right_x, right_y = green_target
                if right_y > 100:
                    steer(STEER_CENTER + ((right_x - 820) * STEER_FACTOR_GREEN_HIGH))
                    print("920")
                else:
                    print("540")
                    steer(STEER_CENTER + ((right_x - 540) * STEER_FACTOR_GREEN_LOW))
        """[The above snipet displays the logic used for obstacle avoidance. We must deviate to the left of the green obstacle. Thus, to our screen, the obstacle must appear on the right. Therefore, out error is the obstacle's current x- the required x (rightx-820) which is multiplied by a Kp (STEER_FACTOR_GREEN_HIGH) and added to the servo's position. Why is it added? Simple, since the servo's centre is 110, and deviations shall have to be added to it. eg( 110 +(-20)) would lead to the servo turning to the 90 position, making our robot move towards the left. Similiarly, if the y of the obstacle is less than 100 (far away), we try and shift the obstacle to the centre of the screen to ensure our robot remain straight. """

"""  [Notice this, both the clockwise and anticlockwise portions are exactly the same! Why? Since we have to go to the left of the green obstacle, and since the preview screen gets practically flipped upon directional switch, there is no need to make any logical changes in the code. However, we still keep the portion in order for any last minute shift changes (820) required."""

"""Teams are advised to change the 820 and 260 shift values as per there needs."""

        elif red_target and rounds_completed <= 12:
            run(SPEED_RUN)
            if CLOCKWISE:
                left_x, left_y = red_target
                if left_y > 100:
                    steer(STEER_CENTER + ((left_x - 260) * STEER_FACTOR_RED_HIGH))
                else:
                    steer(STEER_CENTER + ((left_x - 540) * STEER_FACTOR_RED_LOW))
            else:
                left_x, left_y = red_target
                if left_y > 100:
                    steer(STEER_CENTER + ((left_x - 260) * STEER_FACTOR_RED_HIGH))
                else:
                    steer(STEER_CENTER + ((left_x - 540) * STEER_FACTOR_RED_LOW))
            """[The above snipet displays the logic used for obstacle avoidance. We must deviate to the right of the red obstacle. Thus, to our screen, the obstacle must appear on the left. Therefore, out error is the obstacle's current x- the required x (rightx-260) which is multiplied by a Kp (STEER_FACTOR_RED_HIGH) and added to the servo's position. Why is it added? Simple, since the servo's centre is 110, and deviations shall have to be added to it. eg( 110 +(+20)) would lead to the servo turning to the 130 position, making our robot move towards the right. Similiarly, if the y of the obstacle is less than 100 (far away), we try and shift the obstacle to the centre of the screen to ensure our robot remain straight. """

"""  [Notice this, both the clockwise and anticlockwise portions are exactly the same! Why? Since we have to go to the right of the red obstacle, and since the preview screen gets practically flipped upon directional switch, there is no need to make any logical changes in the code. However, we still keep the portion in order for any last minute shift changes (260) required."""

"""Teams are advised to change the 820 and 260 shift values as per there needs."""          

        else:
            run(SPEED_RUN)
            if left_target and right_target:
                left_x, left_y = left_target
                right_x, right_y = right_target
                if left_y - right_y > 80 and not rounds_completed>12:# if left wall is clearly closer than the right wall
                    steer(STEER_CENTER + (left_x * STEER_FACTOR_LEFT_Y_DIFF))# Go towards the right wall. (Since Error is taken as the left walls' x)
                elif right_y - left_y > 80 and not rounds_completed>12:
                    steer(STEER_CENTER + (right_x * STEER_FACTOR_LEFT_Y_DIFF)) 
          #Move towards the (Error=right wall x) until the left wall is out of frame (since it exits the left_target and right_target condition)
                else:
                    left_val = left_x - LEFT_LIMIT
                    right_val = RIGHT_LIMIT - right_x
                    if left_val < right_val:# This condition occurs when the difference in y is less
                        steer(STEER_CENTER + ((right_val - left_val) * STEER_FACTOR_BLACK_DIFF)) #The robot equalises itself between the 2 walls
                    elif right_val < left_val:
                        steer(STEER_CENTER + ((left_val - right_val) * STEER_FACTOR_BLACK_DIFF)) # robot equalises itself between the 2 walls
                    else:
                        steer(STEER_CENTER) # If both walls can be seen and there y values are same, it means we are straight, so keep going straight
            elif left_target:
                only_x, only_y = left_target
                if rounds_completed >12 and CLOCKWISE: 
                # If rounds completed > 12, begin the outer round wall follow. Since we are going clockwise, we simply allign with it keeping some gap.
                    steer(STEER_CENTER + ((only_x - 420) * STEER_FACTOR_SINGLE_TARGET))
                elif rounds_completed >12:
                    steer(STEER_CENTER + ((only_x) * STEER_FACTOR_SINGLE_TARGET))
                """If rounds completed > 12, begin the outer round wall follow. Since we are going anticlockwise, we should be following the right wall, due to this, we make the error as the left wall's x to instantly move away from it."""    
                else:
                    if CLOCKWISE:
         """If rounds completed are less than 12, and are going clockwise and can only see the left wall, we instantly try and correct ourselves in
         order to see both walls."""
                        steer(STEER_CENTER + ((only_x ) * STEER_FACTOR_SINGLE_TARGET))
                    else:
                #If rounds completed are less than 12, and are going anticlockwise and can only see the left wall, we simply allign ourselves with the wall.
                        steer(STEER_CENTER + ((only_x - 80) * STEER_FACTOR_SINGLE_TARGET))
                        
            elif right_target:
                only_x, only_y = right_target
                if rounds_completed > 12 and CLOCKWISE: # CLOCKWISE
                # When we are taking the outer round, we allign ourselevs with the left wall, thus we take the right wall as the error itself
                    steer(STEER_CENTER + ((only_x) * STEER_FACTOR_SINGLE_TARGET))
                elif rounds_completed > 12: #ANTICLOCKWISE
                    steer(STEER_CENTER + ((only_x - 700) * STEER_FACTOR_OUTER_ROUND))
                # When we are taking the outer round, we allign ourselevs with the right wall, thus we maintain a distance with the right wall      
                else:
                    if CLOCKWISE:
                    #If rounds completed are less than 12, and are going anticlockwise and can only see the right wall, we simply allign ourselves with the wall.
                        steer(STEER_CENTER + ((only_x - 1000) * STEER_FACTOR_SINGLE_TARGET))
                    else:
               """If rounds completed are less than 12, and are going anticlockwise and can only see the right wall, we instantly try and correct ourselves in
         order to see both walls."""
                        steer(STEER_CENTER + ((only_x) * STEER_FACTOR_SINGLE_TARGET))

            else:# If nothing can be seen, on the basis of the direction, we can simply turn that way
                if CLOCKWISE:
                    if rounds_completed >12:
                        steer(STEER_CENTER - 10) # Since we are following the outer wall, we turn slightly to allign with the wall
                    else:
                        steer(STEER_CENTER + 15) # Since we have to go inwards, we turn slightly to allign with the direction we are moving in
                else:
                    if rounds_completed >12:
                        steer(STEER_CENTER + 10)# Since we are following the outer wall, we turn slightly to allign with the wall
                    else:
                        steer(STEER_CENTER - 15)  # Since we have to go inwards, we turn slightly to allign with the direction we are moving in
    else:# Begin parking
        reset_heading()
        if not parked and not CLOCKWISE:# If not already parked and direction is anticlockwise
            # Left forward Until angle -82
            steer(78)
            time.sleep(0.5)
            heading=get_heading()
            while get_heading() > -82: # IMU Based. Teams shall have to change (-82) as per their robot. Decrease for sharper turn, increase for less.
                run(90)
                print("turn1, heading: ",heading)
            stop_robot()
            ########################
            # Straight Back Until IR
            steer(110)
            time.sleep(0.35)
            back(70)
            time.sleep(0.7)
            while (GPIO.input(20)==GPIO.HIGH): #Keep reversing robot until Right Back IR Sensor detects the wall
                back(60)
            stop_robot()
            ########################
            # Forward for 0.3 secs
            run(60)
            time.sleep(0.3) # Time based, go slightly forward. Teams shall have to change this as per their IR sensor placement
            stop_robot()
            time.sleep(0.3)
            ########################
            # Backword until Angle -20 
            steer(72)
            time.sleep(0.5)
            while get_heading() < -20: IMU based. Teams may have to change -20 value. Decrease if turn not enough, increase if turn too much
                back(75)
                print("turn2, heading: ",heading)
            stop_robot()
            #########################
            # Forward until angle -5 IMU based. Teams may have to change -5 value. Decrease if turn not enough. Increase if turn too much
            steer(148)
            while get_heading() <= -5:
                run(75)
                print("turn2, heading: ",heading)
            stop_robot()
            parked=True # Set parked to true so that it does not repeat
            steer(110)
            time.sleep(3)      
            
        if not parked and CLOCKWISE:
                    # Left forward Until angle < 80
            steer(142)
            time.sleep(0.5)
            heading=get_heading()
            while get_heading() < 80: # IMU Based. Teams shall have to change (80) as per their robot. Increase for sharper turn, decrease for less sharp.
                run(90)
                print("turn1, heading: ",heading)
            stop_robot()
            ########################
            # Straight Back Until IR Left Back
            steer(110)
            time.sleep(0.35)
            back(70)
            time.sleep(0.7)
            while (GPIO.input(19)==GPIO.HIGH): #Keep reversing robot until Left Back IR Sensor detects the wall
                back(60)
            stop_robot()
            ########################
            # Forward for 0.3 secs
            run(60)
            time.sleep(0.3) # Time based, go slightly forward. Teams shall have to change this as per their IR sensor placement
            stop_robot()
            time.sleep(0.3)
            ########################
            # Backword until Angle 20 
            steer(142)
            time.sleep(0.5)
            while get_heading() > 20 : IMU based. Teams may have to change 20 value. Increase if turn not enough, decrease if turn too much
                back(75)
                print("turn2, heading: ",heading)
            stop_robot()
            #########################
            # Forward until angle >5 IMU based. Teams may have to change -5 value. Decrease if turn not enough. Increase if turn too much
            steer(78)
            while get_heading() >=5:
                run(75)
                print("turn2, heading: ",heading)
            stop_robot()
            parked=True # Set parked to true so that it does not repeat
            steer(110)
            time.sleep(3)      
           # Since we have to go inwards, we turn slightly to allign with the direction we are moving in

    # Display line count on frame for debugging. Note- Frame rate reduces slightly due to this
    cv2.putText(frame, f"Blue lines: {blue_line_count}", (10, 20), cv2.FONT_HERSHEY_SIMPLEX, 0.6, (255, 0, 0), 2)
    cv2.putText(frame, f"Orange lines: {orange_line_count}", (10, 45), cv2.FONT_HERSHEY_SIMPLEX, 0.6, (0, 140, 255), 2)
    cv2.putText(frame, f"Rounds: {rounds_completed}/{ROUNDS_GOAL}", (10, 70), cv2.FONT_HERSHEY_SIMPLEX, 0.6, (0, 255, 0), 2)

    cv2.imshow("Detection", frame)
    video.write(frame)

def stop_robot():
    stop_motors()
    steer(STEER_CENTER)

# === Main loop ===
start = False
stop = True

try:
    reset_heading()
    while True:
        if pi.read(BUTTON_START) == 1 and stop:# If start button is pressed, set variable start to 'True' and stop to 'False'
            
            start = True
            stop = False
            print("Start pressed")
        if pi.read(BUTTON_STOP) == 1 and start: #If stop button is pressed, set variable start to 'False and stop to 'True'
            start = False
            stop = True
            print("Stop pressed")
            reset_heading() 

        if start:# run the function of wall following, line counting, obstacle avoiding and parking
            process_frame()
        else:
            stop_robot() # stop the robot

        if cv2.waitKey(1) & 0xFF == ord('q'): #if q is pressed, then code may be stopped
            break

except KeyboardInterrupt:
    print("Exiting...")

finally:
    stop_robot() # set speed to 0
    cv2.destroyAllWindows() #shut camera preview
    video.release() # save the video recorded
    picam2.stop() # stop camera
    pi.stop() # stop motor pins
    GPIO.cleanup() # reset GPIO pin states and values

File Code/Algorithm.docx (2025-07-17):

Open Challenge Algorithm:

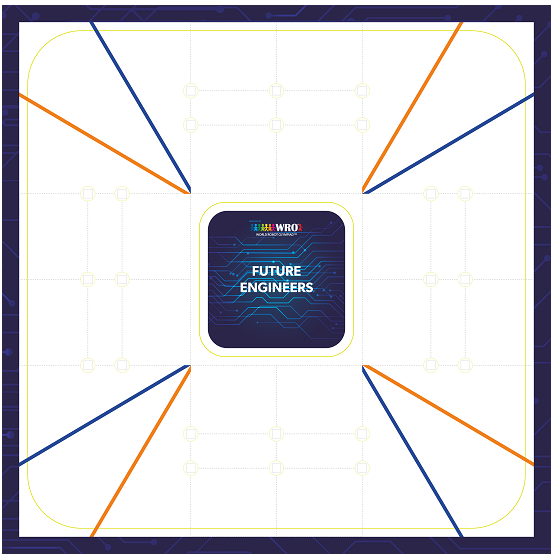
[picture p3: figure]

The Open Challenge presents an interesting and exciting opportunity to push the limits of camera-detection and speed. We utilize this to our advantage and rather than using various sensors (ultrasonic and imu) whose values have to be passed down and filtered, use a single camera and a color sensor to detect the lines.

Detection [Black Walls]

We use a camera to detect the black walls on either side [color based] and accordingly set the direction of the robot. Using OpenCV, we ensure that only 1 black wall on either side (left and right) can be detected. Furthermore, we crop out the frame in front to omit detection of the front black walls. We compare the distance between either walls from the center and accordingly calculate the error distance between the walls, thus understanding the robot’s offset from the center. If at any point, both walls cannot be detected, the robot shall automatically turn enough so that it can detect the other wall. In order to account for this, we implement a PD [proportional derivative] logic. This is acted upon the steering servo which accordingly changes the direction of the steering wheels.

Corner Turning

By using the difference between the walls to set the direction, we eliminate the need for any non-sensor based logic. Upon reaching the corner, the camera can no longer detect one of the walls. As a result of this, in order to maintain its center position, the robot turns towards the side where the wall cannot be detected. As it keeps turning, it manages to find the equality between both walls again and continues using the PD algorithm to maintain a center position.

Round Count

In order to understand how many rounds have elapsed, we use the color sensor to detect the corner lines. In order to omit any sort of detection error, we look for both blue and orange. After detection, we disable the sensor for some time so that multiple detections do not occur. After counting 24 such lines, we establish that 3 rounds have been completed. [2 detections per corner, 4 corners, 3 rounds].

Obstacle Challenge Algorithm:

The Obstacle Challenge, provides a challenging problem to which several algorithms must be implemented to ensure a consistent success rate. We take reference from both the black walls, and the obstacles themselves, in order to find the correct path to navigate through the walls and obstacles without any failure.

(Clockwise):

Detection [Red & Green Obstacle]

If both obstacles are detected, we establish which one is closer by comparing the Y value and accordingly take reference from the closer one. After that we use the algorithm of either the green or red obstacle.

Detection [Red Obstacle]

When the red obstacle is detected, we immediately take reference from it. It is detected by using a combination of both HSV values and a minimum area requirement. A boundary box is then drawn around it. Our field of view from the camera is 1020 x 300. We implement a number of steps to ensure consistent maneuvering. Firstly, we check the distance between the camera and the obstacle by comparing the Y value. The higher the value is, the closer it is to the robot. [If the Y value is too high, we reverse the robot until the Y value reduces enough]. According to the distance between the robot and the obstacle along with the X value of the obstacle, we turn it accordingly to the left. My multiplying the Y value and the 1020-X value by a constant amount (j), we accordingly turn the robot. The distance between the obstacle and turning effect is inversely proportional. We tune the ‘j’ value so that the turning effect is successful. This turning effect uses a PD Algorithm.

Detection [Green Obstacle]

When the green obstacle is detected, we immediately take reference from it. It is detected by using a combination of both HSV values and a minimum area requirement. A boundary box is then drawn around it. Our field of view from the camera is 1020 x 300. We implement a number of steps to ensure consistent maneuvering. Firstly, we check the distance between the camera and the obstacle by comparing the Y value. The higher the value is, the closer it is to the robot. [If the Y value is too high, we reverse the robot until the Y value reduces enough]. According to the distance between the robot and the obstacle along with the X value of the obstacle, we turn it accordingly to the left. My multiplying the Y value and the X value by a constant amount (j), we accordingly turn the robot. The distance between the obstacle and turning effect is inversely proportional. We tune the ‘k’ value so that the turning effect is successful. This turning effect uses a PD Algorithm.

Detection [No Obstacle]

If no obstacle is detected, we immediately switch to the wall following logic and ensure constant distance between the walls.

Detection [Black Walls & No Obstacle]

We use a camera to detect the black walls on either side [color based] and accordingly set the direction of the robot. Using OpenCV, we ensure that only 1 black wall on either side (left and right) can be detected. Furthermore, we crop out the frame in front to omit detection of the front black walls. We compare the distance between either walls from the center and accordingly calculate the error distance between the walls, thus understanding the robot’s offset from the center. In order to account for this, we implement a PD [proportional derivative] logic. This is acted upon the steering servo which accordingly changes the direction of the steering wheels.

Detection [Singular Black Wall]

If at any point, both walls cannot be detected, the robot shall automatically turn enough so that it can detect the other wall, due to the PD logic.

Round Count

In order to understand how many rounds have elapsed, we use the color sensor to detect the corner lines. In order to omit any sort of detection error, we look for both blue and orange. After detection, we disable the sensor for some time so that multiple detections do not occur. After counting 24 such lines, we establish that 3 rounds have been completed. [2 detections per corner, 4 corners, 3 rounds].

Detection of Parking

During the 3 rounds we take, we ensure that the red obstacles and magenta parking walls are not confused using a special logic. Since the HSV values are very similar, we also implement a minimum area logic. The area of the walls are less compared to the obstacles and are thus, omitted while the rounds are going on. After completion of the rounds, we reverse the logic and ensure that only if the area is less than a certain value, is the parking detected.

Parking

Due to our great turning radius, parking becomes very simple in our case. By using our camera to ensure we are in the middle of the walls, we then ensure that the back of the robot is facing the outer wall of the mat (not of the parking walls). We then bang against the wall to ensure a fixed position. Then, we use a fixed set of a combination of 3 turns to park.

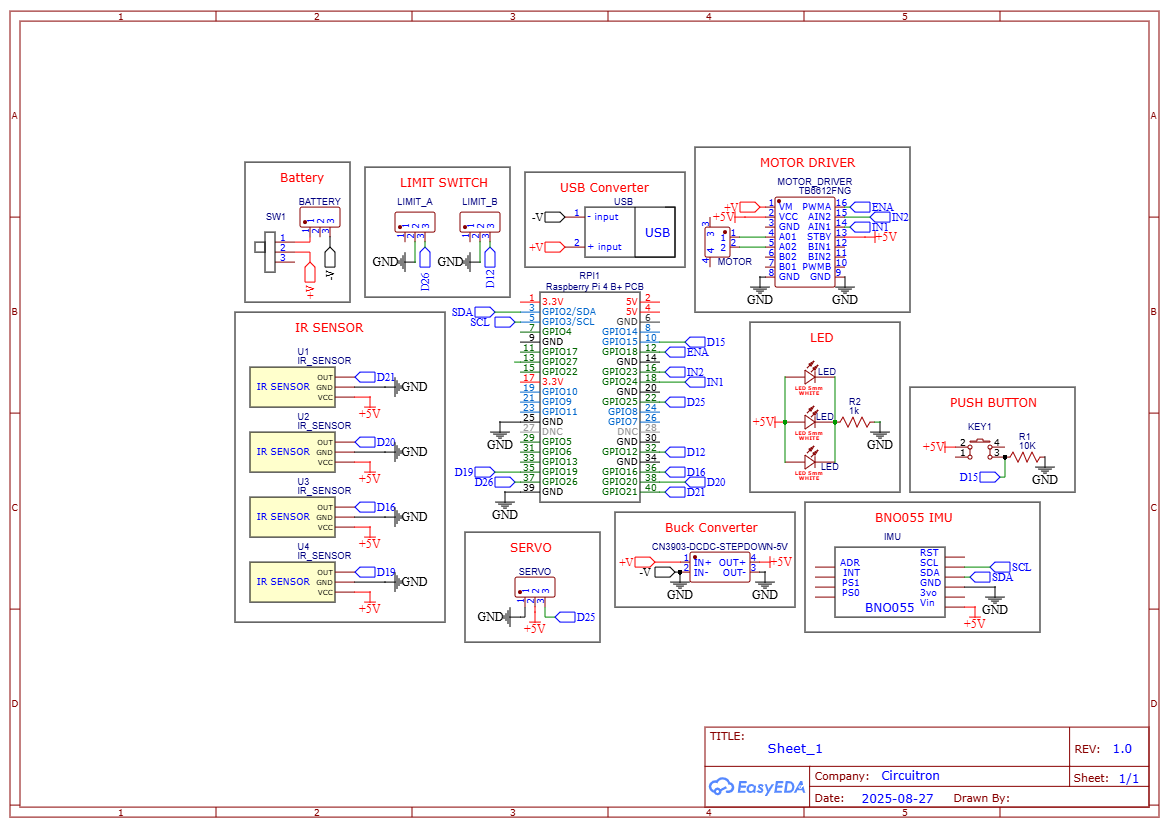
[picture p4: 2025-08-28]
Hardware/Schematic Diagram.png

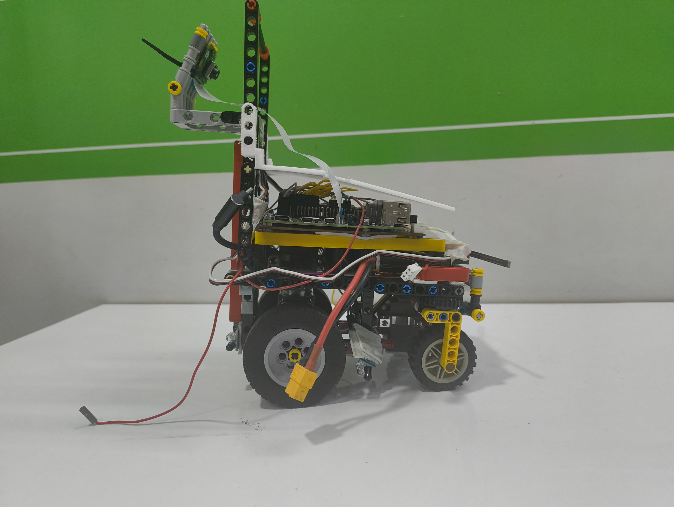
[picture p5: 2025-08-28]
v-photos/left view.jpg

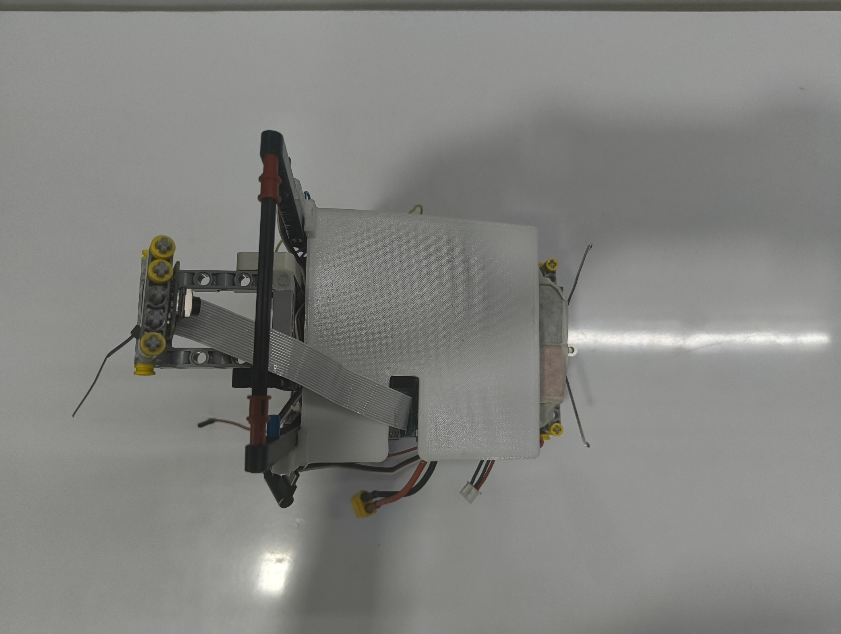
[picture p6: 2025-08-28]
v-photos/top view.jpg

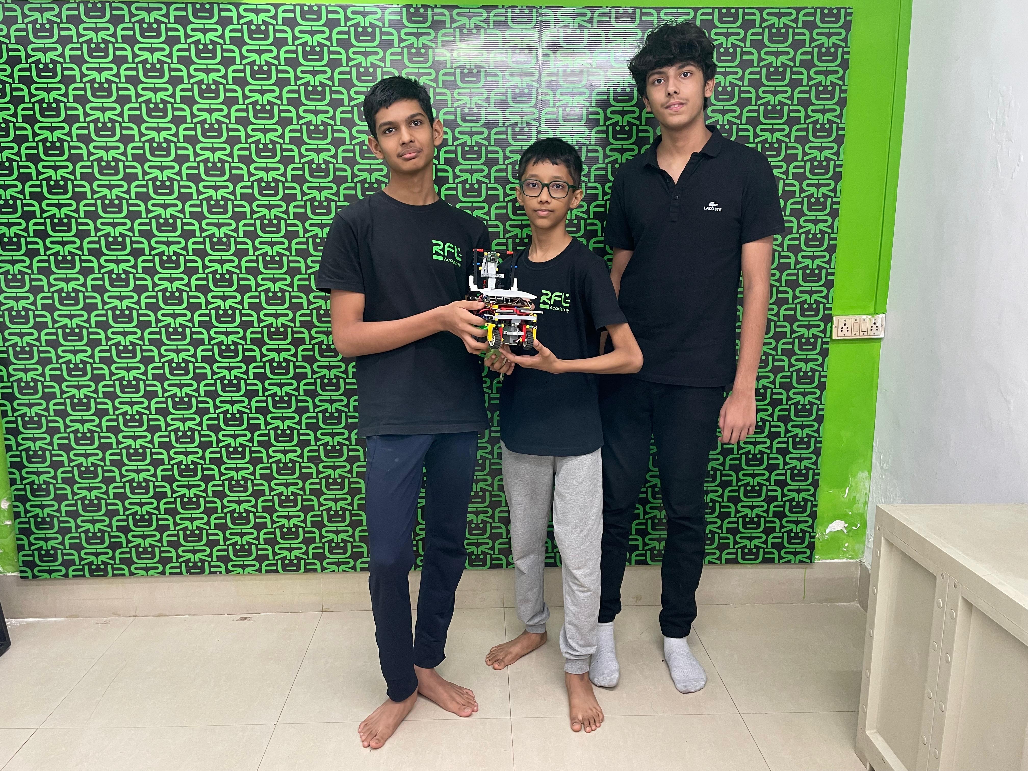
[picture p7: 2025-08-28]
t-photos/team_photo.jpg

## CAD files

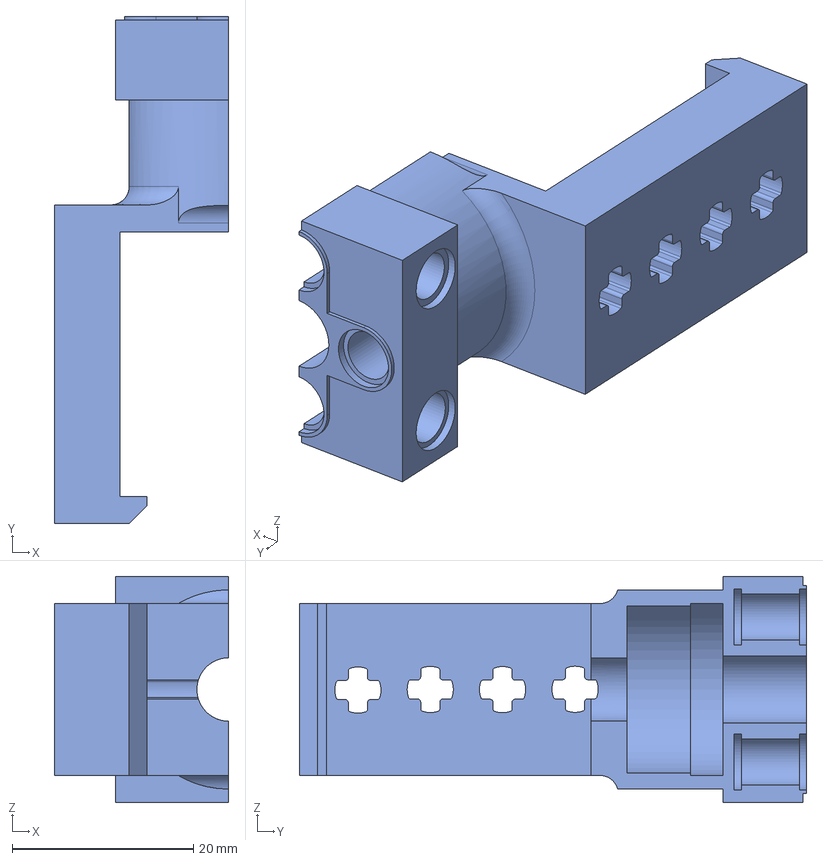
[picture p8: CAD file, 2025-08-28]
Hardware/Custom Motor mount.step
19.2 x 56.0 x 25.0 mm

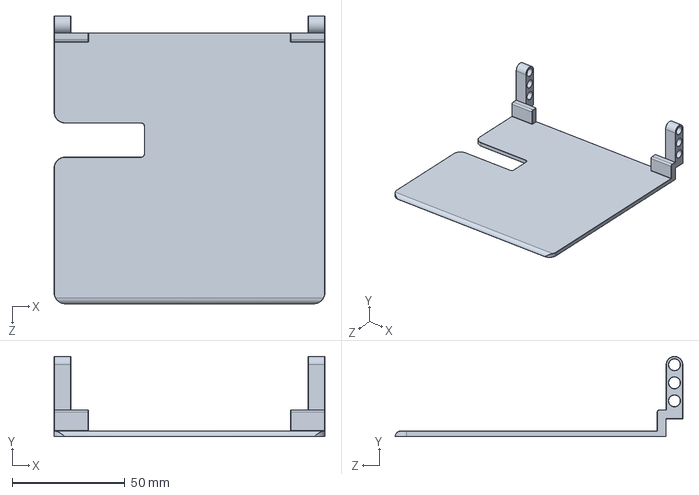
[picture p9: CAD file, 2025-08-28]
Hardware/Top Cover.STEP
120.0 x 35.5 x 127.4 mm

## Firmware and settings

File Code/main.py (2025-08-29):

from picamera2 import Picamera2
import cv2
import numpy as np
import time
import pigpio
import datetime
import board
import adafruit_bno055
import RPi.GPIO as GPIO
# === I2C & sensors ==
i2c = board.I2C()
sensor = adafruit_bno055.BNO055_I2C(i2c)
button_state=None
offset = 0
prev_heading = None
total_heaeding = 0
# === Pin and hardware config ===
MOTOR_PIN_1 = 24
MOTOR_PIN_2 = 23
MOTOR_ENA = 18
SERVO_PIN = 25
BUTTON_START = 14
BUTTON_STOP = 15
total_heading=0
ParkOver=False
# Motor PWM frequency
MOTOR_PWM_FREQ = 1000
BUTTON_PIN = 26  # Change to the GPIO pin you connected the button to

GPIO.setmode(GPIO.BCM)
GPIO.setup(BUTTON_PIN, GPIO.IN, pull_up_down=GPIO.PUD_UP)
GPIO.setup(12,GPIO.IN,pull_up_down=GPIO.PUD_UP)
GPIO.setup(21,GPIO.IN)
GPIO.setup(20,GPIO.IN)
# Speed settings (0-255 PWM duty cycle)
SPEED_RUN = 80 # 90
SPEED_RUN_SLOW = 75
SPEED_STOP = 0

# Steering angles (degrees)
STEER_CENTER = 110
STEER_LEFT_LIMIT = 78
STEER_RIGHT_LIMIT = 142

# Steering adjustment factors (tuning)
STEER_FACTOR_GREEN_HIGH =0.09
STEER_FACTOR_GREEN_LOW = 0.07
STEER_FACTOR_RED_HIGH = 0.09
STEER_FACTOR_RED_LOW = 0.07
STEER_FACTOR_BLACK_DIFF = 0.07
STEER_FACTOR_SINGLE_TARGET = 0.08
STEER_FACTOR_OUTER_ROUND=0.04
STEER_FACTOR_LEFT_Y_DIFF = 0.07


# STEER_FACTOR_GREEN_HIGH=0.07
# STEER_FACTOR_GREEN_LOW = 0.07
# STEER_FACTOR_RED_HIGH = 0.06
# STEER_FACTOR_RED_LOW = 0.07
# STEER_FACTOR_BLACK_DIFF = 0.08
# STEER_FACTOR_SINGLE_TARGET = 0.04
# STEER_FACTOR_LEFT_Y_DIFF = 0.07

# Camera settings
EXPOSURE_TIME =13000
X_RESOL = 1080
Y_RESOL = 300
X_MID = X_RESOL / 2
LEFT_LIMIT = 10
RIGHT_LIMIT = X_RESOL - 10

# HSV thresholds for colors
GREEN_LOWER = np.array([50, 100, 50])
GREEN_UPPER = np.array([70, 255, 255])

RED_LOWER1 = np.array([0, 120, 50])
RED_UPPER1 = np.array([10, 255, 255])
RED_LOWER2 = np.array([160, 120, 50])
RED_UPPER2 = np.array([165, 255, 255])

PINK_LOWER = np.array([160, 100, 120])
PINK_UPPER = np.array([175, 255, 255])

BLACK_LOWER = np.array([0, 0, 0])
BLACK_UPPER = np.array([179, 255, 50])

BLUE_LOWER = np.array([100, 150, 50])
BLUE_UPPER = np.array([130, 255, 255])

ORANGE_LOWER = np.array([10, 150, 100])
ORANGE_UPPER = np.array([25, 255, 255])

PURPLE_LOWER = np.array([160, 80, 40])
PURPLE_UPPER = np.array([175, 255, 200])
# Line detection parameters
LINE_COOLDOWN = 3.5  # seconds cooldown before recounting same line
LINE_DETECT_REGION_Y =Y_RESOL-50  # y coordinate near bottom to detect line crossing

# Stop timer duration after rounds complete (seconds)
STOP_TIMER_DURATION = 3
CamOn=True
# Number of rounds robot must complete before stopping
ROUNDS_GOAL = 14

ButtonTime=0

# Line counting mode: 'blue', 'orange', or 'both'
LINE_COUNT_MODE = 'both'  # Change this to 'blue' or 'orange' as needed

# === Initialize PiCamera2 ===
picam2 = Picamera2()
preview_config = picam2.create_preview_configuration(main={"format": 'RGB888', "size": (X_RESOL, Y_RESOL)})
picam2.preview_configuration.controls.FrameRate = 60
picam2.configure(preview_config)
picam2.set_controls({
    "AeEnable": False,
    "ExposureTime": EXPOSURE_TIME,
    "AnalogueGain": 4.0
})
timestamp = datetime.datetime.now()
video = cv2.VideoWriter(f"output{timestamp}.mp4", cv2.VideoWriter_fourcc(*"mp4v"), 20, (X_RESOL, Y_RESOL))
picam2.start()
time.sleep(1)

# === Setup GPIO pins ===
pi = pigpio.pi()
pi.set_mode(BUTTON_START, pigpio.INPUT)
pi.set_pull_up_down(BUTTON_START, pigpio.PUD_UP)
pi.set_mode(BUTTON_STOP, pigpio.INPUT)
pi.set_pull_up_down(BUTTON_STOP, pigpio.PUD_UP)

for pin in (MOTOR_PIN_1, MOTOR_PIN_2, MOTOR_ENA):
    pi.set_mode(pin, pigpio.OUTPUT)
    pi.write(pin, 0)

pi.set_PWM_frequency(MOTOR_ENA, MOTOR_PWM_FREQ)

# === Robot control functions ===
def steer(angle: float):
    """Set servo angle within limits."""
    angle = max(STEER_LEFT_LIMIT, min(STEER_RIGHT_LIMIT, angle))
    pulse = int(500 + (angle / 180) * 2000)
    pi.set_servo_pulsewidth(SERVO_PIN, pulse)

def run(speed: int):
    """Run motors forward at speed (0-255)."""
    pi.write(MOTOR_PIN_1, 1)
    pi.write(MOTOR_PIN_2, 0)
    pi.set_PWM_dutycycle(MOTOR_ENA, speed)

def back(speed: int):
    """Run motors backward at speed (0-255)."""
    pi.write(MOTOR_PIN_1, 0)
    pi.write(MOTOR_PIN_2, 1)
    pi.set_PWM_dutycycle(MOTOR_ENA, speed)

def stop_motors():
    """Stop all motors."""
    pi.set_PWM_dutycycle(MOTOR_ENA, 0)
    pi.write(MOTOR_PIN_1, 0)
    pi.write(MOTOR_PIN_2, 0)
def reset_heading():
    global prev_heading,total_heading
    prev_heading = None
    total_heading = 0
def get_heading():
    global total_heading,prev_heading
    try:
        time.sleep(0.03)
        current_heading = sensor.euler[0]
        if current_heading is None:
            return total_heading

        if prev_heading is None:
            prev_heading = current_heading
            return total_heading

        delta = current_heading - prev_heading
        if delta > 180:
            delta -= 360
        elif delta < -180:
            delta += 360

        total_heading += delta
        prev_heading = current_heading
        return total_heading
    except Exception as e:
        print("Error reading heading:", e)
        return total_heading
def get_red_mask(hsv):
    """Get combined red mask handling hue wrap."""
    mask1 = cv2.inRange(hsv, RED_LOWER1, RED_UPPER1)
    mask2 = cv2.inRange(hsv, RED_LOWER2, RED_UPPER2)
    return cv2.bitwise_or(mask1, mask2)

# === Global variables for line counts and cooldown ===
blue_line_count = 0
orange_line_count = 0
last_blue_time = 0
last_orange_time = 0

# Rounds & stopping control
rounds_completed = 0
stop_start_time = None
stop_motor_done = False
insidePark=True
targ1 = True
targ2 = True
targ3=True
targ4=True
selected = False
CLOCKWISE = True
over = False
parked = False
Reset=False
# === Main processing function ===
def process_frame():
    global ButtonTime, Reset, STEER_FACTOR_OUTER_ROUND
    global blue_line_count, orange_line_count, last_blue_time, last_orange_time,purple_target
    global rounds_completed, stop_start_time, stop_motor_done,selected,CLOCKWISE
    global targ1,targ2,insidePark,targ3,targ4,parked,over
    frame = picam2.capture_array()
    hsv = cv2.cvtColor(frame, cv2.COLOR_BGR2HSV)
    blur = cv2.GaussianBlur(hsv, (5, 5), 0)
    current_time = time.time()
    black_mask = cv2.inRange(blur, BLACK_LOWER, BLACK_UPPER)
    green_mask = cv2.inRange(blur, GREEN_LOWER, GREEN_UPPER)
    red_mask = get_red_mask(hsv)
    pink_mask = cv2.inRange(blur, PINK_LOWER, PINK_UPPER)
    blue_mask = cv2.inRange(hsv, BLUE_LOWER, BLUE_UPPER)
    orange_mask = cv2.inRange(hsv, ORANGE_LOWER, ORANGE_UPPER)
    purple_mask = cv2.inRange(hsv, PURPLE_LOWER, PURPLE_UPPER)
    
    kernel_5 = np.ones((5, 5), np.uint8)
    kernel_50 = np.ones((50, 50), np.uint8)

    black_mask = cv2.morphologyEx(black_mask, cv2.MORPH_CLOSE, kernel_50)
    black_mask = cv2.morphologyEx(black_mask, cv2.MORPH_DILATE, kernel_50)
    blue_mask = cv2.morphologyEx(blue_mask, cv2.MORPH_CLOSE, kernel_5)
    orange_mask = cv2.morphologyEx(orange_mask, cv2.MORPH_CLOSE, kernel_5)

    # Blue line detection
    global ParkOver
    blue_detected = False
    blueDone=0
    if LINE_COUNT_MODE in ('blue', 'both'):
        contours_blue, _ = cv2.findContours(blue_mask, cv2.RETR_EXTERNAL, cv2.CHAIN_APPROX_SIMPLE)
        for cnt in contours_blue:
            if cv2.contourArea(cnt) > 1000 and ParkOver:
                x, y, w, h = cv2.boundingRect(cnt)
                if y + h >= LINE_DETECT_REGION_Y:
                    blue_detected = True
                    cv2.rectangle(frame, (x, y), (x + w, y + h), (255, 0, 0), 2)
                    break

    # Orange line detection
    orange_detected = False
    orangeDone=0
    if LINE_COUNT_MODE in ('orange', 'both'):
        contours_orange, _ = cv2.findContours(orange_mask, cv2.RETR_EXTERNAL, cv2.CHAIN_APPROX_SIMPLE)
        for cnt in contours_orange:
            if cv2.contourArea(cnt) > 1000 and ParkOver:
                x, y, w, h = cv2.boundingRect(cnt)
                if y + h >= LINE_DETECT_REGION_Y:
                    orange_detected = True
                    cv2.rectangle(frame, (x, y), (x + w, y + h), (0, 140, 255), 2)
                    break

    if blue_detected and (current_time - last_blue_time) > LINE_COOLDOWN:        
        if GPIO.input(26)==GPIO.LOW or GPIO.input(12)==GPIO.LOW:
            blue_line_count-=1
        blue_line_count += 1
        last_blue_time = current_time
        print(f"Blue line crossed! Count: {blue_line_count}")

    if orange_detected and (current_time - last_orange_time) > LINE_COOLDOWN:       
        if GPIO.input(26)==GPIO.LOW or GPIO.input(12)==GPIO.LOW:
            orange_line_count-=1
        orange_line_count += 1
        last_orange_time = current_time
        print(f"Orange line crossed! Count: {orange_line_count}")
    
    # Calculate rounds completed
    if LINE_COUNT_MODE == 'blue':
        rounds_completed = blue_line_count
    elif LINE_COUNT_MODE == 'orange':
        rounds_completed = orange_line_count
    else:  # both
        rounds_completed = max(blue_line_count, orange_line_count)

    global stop_start_time, stop_motor_done
    
    # Find black contours for navigation
    contours, _ = cv2.findContours(black_mask, cv2.RETR_EXTERNAL, cv2.CHAIN_APPROX_SIMPLE)
    left_target = None
    right_target = None
    max_left_y = 0
    max_right_y = 0

    for contour in contours:
        area = cv2.contourArea(contour)
        if area > 1000:
            x, y, w, h = cv2.boundingRect(contour)
            cx = int(x + w / 2)
            cy = int(y + h / 2)
            cv2.rectangle(frame, (x, y), (x + w, y + h), (180, 105, 255), 2)
            cv2.circle(frame, (cx, cy), 5, (255, 0, 0), -1)
            if not selected:
                if cx < X_MID:
                    CLOCKWISE = True
                else:
                    CLOCKWISE = False
                selected = True
            if CLOCKWISE:
                if cx <= X_MID + 10 and cy > max_left_y: # 100
                    max_left_y = cy
                    left_target = (x + w, y + h)
                elif cx > X_MID + 10 and cy > max_right_y: # 100
                    max_right_y = cy
                    right_target = (x, y + h)
            else:
                if cx >= X_MID - 10 and cy > max_right_y: # -100
                    max_right_y = cy
                    right_target = (x, y + h)
                elif cx < X_MID - 10 and cy > max_left_y: # -100
                    max_left_y = cy
                    left_target = (x + w, y + h) # 
                
    # Detect green obstacles
    green_contours, _ = cv2.findContours(green_mask, cv2.RETR_EXTERNAL, cv2.CHAIN_APPROX_SIMPLE)
    green_target = None
    green_y = 0
    for c in green_contours:
        area = cv2.contourArea(c)
        if 1000 < area <= 20000:
            x, y, w, h = cv2.boundingRect(c)
            cx = x
            cy = y + h
            cv2.rectangle(frame, (x, y), (x + w, y + h), (0, 255, 0), 2)
            cv2.circle(frame, (cx, cy), 5, (255, 0, 0), -1)
            cv2.putText(frame, f"Green Obstacle: {cy}", (x, y - 10), cv2.FONT_HERSHEY_SIMPLEX, 0.6, (0, 255, 0), 2)
            if CLOCKWISE:
                if cy > green_y:
                    green_y = cy
                    green_target = (cx, cy)
                    if rounds_completed >= 12:
                        right_target = (cx, cy)
            else:
                if cy > green_y:
                    green_y = cy
                    green_target = (cx, cy)
                    if rounds_completed >= 12:
                        left_target = (cx, cy)
            
    # Detect red obstacles
    red_contours, _ = cv2.findContours(red_mask, cv2.RETR_EXTERNAL, cv2.CHAIN_APPROX_SIMPLE)
    red_target = None
    red_y = 0
    for c in red_contours:
        area = cv2.contourArea(c)
        if area > 1000:
            x, y, w, h = cv2.boundingRect(c)
            cx = x + w
            cy = y + h
            cv2.rectangle(frame, (x, y), (x + w, y + h), (0, 0, 255), 2)
            cv2.circle(frame, (cx, cy), 5, (255, 0, 0), -1)
            cv2.putText(frame, f"Red Obstacle:{cy}", (x, y - 10), cv2.FONT_HERSHEY_SIMPLEX, 0.6, (0, 0, 255), 2)
            if CLOCKWISE:
                if cy > red_y:
                    red_y = cy
                    red_target = (cx, cy)
                    if rounds_completed >= 12:
                        right_target = (cx,cy)
            else:
                if cy > red_y :
                    red_y = cy
                    red_target = (cx, cy)
                    if rounds_completed >= 12:
                        left_target = (cx,cy)

    current_time = time.time()
    global button_state
    purple_detected = False
    purple_target = None
    global timestart
    timestart=time.time()
    contours_purple, _ = cv2.findContours(purple_mask, cv2.RETR_EXTERNAL, cv2.CHAIN_APPROX_SIMPLE)
    for cnt in contours_purple:
        x, y, w, h = cv2.boundingRect(cnt)         
        if cv2.contourArea(cnt) > 1000:
            if CLOCKWISE:
                purple_detected = True
                cv2.rectangle(frame, (x, y), (x + w, y + h), (180, 105, 255), 2)
                cv2.circle(frame, (x+w, y), 5, (255, 0, 0), -1)
                left_target = (x+w, y)
                purple_target = (x+w, y)
            else:
                purple_detected = True
                cv2.rectangle(frame, (x, y), (x + w, y + h), (180, 105, 255), 2)
                cv2.circle(frame, (x, y), 5, (255, 0, 0), -1)
                right_target = (x, y)
                purple_target = (x, y)
            

    # Update line counts with cooldowns
    # Stop timer handling
    if not over:
        print("Heading : ",abs(get_heading()))
        if insidePark:
            if CLOCKWISE:
                if abs(get_heading()) < 20 and targ1:
                    steer(72)
                    back(85)
                elif abs(get_heading()) < 50 and targ2:
                    targ1 = False
                    steer(148)
                    run(85)
                elif abs(get_heading())>5 and targ3:
                    targ2=False
                    steer(72)
                    run(85)
                else:
                    targ3=False
                    if targ3==False and targ4:
                        run(0)
                        steer(110)
                        time.sleep(0.5)
                        back(100)
                        time.sleep(1)
                        targ4=False
                        insidePark=False
                        time.sleep(0.5)
                        stop_robot()
                        
            else:
                if abs(get_heading()) <15 and targ1:
                    steer(148)
                    back(85)
                
                elif abs(get_heading()) <50 and targ2:
                    targ1 = False
                    steer(72)
                    run(85)
                elif abs(get_heading()) >10 and targ3:
                    targ2=False
                    steer(148)
                    run(85)                                 
                else:
                    targ3=False
                    targ2 = False
                    if targ3==False and targ4:
                        run(0)
                        steer(110)
                        time.sleep(0.5)
                        back(100)
                        time.sleep(1.4)
                        targ4=False
                        insidePark=False
                        run(0)
                        time.sleep(0.45)
                        stop_robot()
                        time.sleep(0.5)
                        ParkOver=True
                        
        elif GPIO.input(12)==GPIO.LOW:
            ButtonTime=time.time()
            run(0)
            time.sleep(0.3)
            steer(142)
            time.sleep(0.4)
            back(90)
            time.sleep(0.5)
            run(0)
            time.sleep(0.4)
            steer(110)
            time.sleep(0.4)
#             back(80)
#             time.sleep(0.4)
#             run(0)
#             time.sleep(0.4)
        elif GPIO.input(26)==GPIO.LOW:
            ButtonTime=time.time()
            run(0)
            time.sleep(0.3)
            steer(78)
            time.sleep(0.4)
            back(90)
            time.sleep(0.5)
            run(0)
            time.sleep(0.4)
            steer(110)
            time.sleep(0.4)
#             back(80)
#             time.sleep(0.4)
#             run(0)
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

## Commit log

2025-06-28 Update README.md
    This repository contains details about the design, evolution, and continuous development of our self-driving robot vehicle, built and programmed by Team Circuitron for the Future Engineers 2024 categ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
2025-07-19 Rename Start.png to Obstacle Challenge Flowchart.png
2025-07-19 Rename Copy of Start.png to Open Challenge Flowchart.png
2025-08-24 Rename robot updated_12_45_25_copy.pdf to Robot assembly instuctions
2025-08-27 Update Robot assembly instuctions
2025-09-02 The Making of Voltaris
